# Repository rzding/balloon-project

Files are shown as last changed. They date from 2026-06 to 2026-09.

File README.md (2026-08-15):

# SSI high-altitude balloon project

**Firmware:** [`balloon-project-stm32mx/`](balloon-project-stm32mx/) — STM32F411 flight-computer firmware (build, flash, and coding standards).

**Standards and phases:** [`Software Documents/Main Developmental Roadmap.md`](Software%20Documents/Main%20Developmental%20Roadmap.md)

**Verification workflow:** [`Software Documents/Firmware Development Guidelines.md`](Software%20Documents/Firmware%20Development%20Guidelines.md) — deferred hardware, host tests, bench backlog (roadmap §21). Software-complete unblocks the next driver phase; hardware exit is ticked during bring-up week, not before coding the next phase.

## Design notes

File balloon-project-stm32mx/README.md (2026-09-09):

# STM32 flight-computer firmware

STM32F411CEU6 firmware for the SSI high-altitude balloon flight computer. CubeMX generates `Core/`; application code lives in `App/`.

## Coding standards

Follow [Software Documents/Main Developmental Roadmap.md](../Software%20Documents/Main%20Developmental%20Roadmap.md) **§3** (architecture and coding practices) and [Firmware Development Guidelines.md](../Software%20Documents/Firmware%20Development%20Guidelines.md) (verification, deferred HW, host tests). In short:

- Layered design: `main` → `app_init` / `app_run` → drivers → `spi_bus` → HAL
- Edit CubeMX output only inside `/* USER CODE BEGIN/END */` blocks
- One device = one module (`foo.c` / `foo.h`); public APIs use `bool *_init(void)` and read/poll functions
- Fail-operational: set `error_flags`; never block the mission loop on subsystem faults
- No `malloc` in the flight loop; fixed-size buffers; finite HAL timeouts
- Deferred hardware checks: track in roadmap **§21 Bench verification backlog** until bring-up week. Software-complete of a phase unblocks the next driver phase; HW exit stays in §21 until the board is exercised.

**Host unit tests** (pure logic, no HAL): `tests/host/` — run manually; see `tests/host/README.md`. Cursor agents document run commands but do not execute tests by default.

`.clang-format` is deferred (not required for Phase F0).

## Build

From this directory:

```bash
make clean && make
```

Requires `arm-none-eabi-gcc` (e.g. STM32CubeCLT). Artifacts are written to `build/` (gitignored):

- `build/balloon-project-stm32mx.elf`
- `build/balloon-project-stm32mx.hex`
- `build/balloon-project-stm32mx.bin`

### APRS dry-run vs RF (F10.4 / O6)

Default build is **dry-run** (`APRS_RF_ENABLE=0`): the APRS state machine still encodes and may drive AFSK on PA0, but **PTT stays high** (no RF). Inspect `g_aprs_last_info` / `g_aprs_ok` under GDB. Host proof of frame encode: `tests/host` → `./test_aprs_ax25`.

Licensed on-air only:

```bash
make clean && make APRS_RF_ENABLE=1
```

Do not enable RF without a callsign and license.

## Add a new App module

1. Add `App/Inc/foo.h` and `App/Src/foo.c` (one module = one `.c` / `.h` pair).
2. List `App/Src/foo.c` in Makefile `C_SOURCES` (re-add App entries after CubeMX Makefile regen).
3. `#include "foo.h"` from callers; `-IApp/Inc` is already in `C_INCLUDES`.
4. Regenerate IDE IntelliSense DB: `make compile_commands`.

## IDE IntelliSense (Cursor / VS Code)

Repo-root workspace config (keeps editor diagnostics aligned with the Makefile):

- `compile_commands.json` — same defines/includes as `make`
- `.clangd` — clangd + `arm-none-eabi-gcc` query-driver
- Repo `.vscode/c_cpp_properties.json` + `.vscode/settings.json`

After adding App sources, run `make compile_commands`, then **Developer: Reload Window** if squiggles remain.

## SWD / flash

**Hardware:** ST-Link (or Nucleo as SWD bridge) to the flight-computer SWD header (SWDIO, SWDCLK, GND, 3V3, NRST as wired on the PCB).

**Tooling (any one):**

- STM32CubeProgrammer — flash `build/balloon-project-stm32mx.elf` or `.bin`
- `st-flash write build/balloon-project-stm32mx.bin 0x08000000`
- OpenOCD + GDB — load `build/balloon-project-stm32mx.elf`

**Expected behavior after reset:** `main` → peripheral init → `app_init()` → `while (1) { app_run(); }`

## Layout

```text
balloon-project-stm32mx/
  Core/          # CubeMX — edit ONLY USER CODE regions
  App/
    Inc/         # Public headers per module
    Src/         # One .c per module
  Makefile       # Every App/Src/*.c listed; -IApp/Inc
```

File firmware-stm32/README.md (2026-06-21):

Folder containing all firmware code for STM32 Computer

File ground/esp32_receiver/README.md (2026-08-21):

# ESP32 ground station receiver

Receives packet v1 telemetry from the flight computer's RFM95W and prints decoded
fields over USB serial. No WiFi or BLE — the ESP32 stays wired to the laptop.

Sketch: [`esp32_receiver.ino`](esp32_receiver.ino)

## Hardware

| Item | Notes |
|---|---|
| ESP32 dev board | any; pins below are remappable |
| Adafruit RFM95W LoRa breakout | product [3072](https://www.adafruit.com/product/3072), 915 MHz |
| 915 MHz antenna | 3.12" (~79 mm) solid-core wire on the ANT pad, or SMA |

The breakout has an onboard 3.3 V regulator and level shifting, so it is 3–6 V
tolerant on Vin and safe on the ESP32's 3.3 V logic.

## Wiring

| Breakout | ESP32 | Notes |
|---|---|---|
| Vin | 3V3 | regulated on-board |
| GND | GND | |
| EN | *not connected* | pulled high to Vin by default |
| SCK | D18 | |
| MISO | D19 | |
| MOSI | D15 | remapped via the GPIO matrix |
| CS | D5 | |
| RST | D4 | library pulses this low to reset the radio |
| G0 | *not connected* | see below |
| ANT | antenna | **required — do not transmit or receive without one** |
| DIO1–DIO5 | *not connected* | |

`G0` (DIO0) is unused because the sketch polls with `LoRa.parsePacket()` rather
than using an interrupt. If you switch to `LoRa.onReceive()`, wire G0 to a
general-purpose pin and set `PIN_DIO0`.

**Avoid GPIO2 for G0.** It is a boot-strapping pin, and G0 is driven by the
radio, so the radio could hold it at an arbitrary level while the ESP32 is
deciding how to boot.

## Software setup

1. **ESP32 board support** — Arduino IDE → Settings → *Additional Board Manager
   URLs*:
   ```
   https://espressif.github.io/arduino-esp32/package_esp32_index.json
   ```
   Then Tools → Board → Boards Manager → install **esp32 by Espressif Systems**.

2. **Library** — Tools → Manage Libraries → install **LoRa by Sandeep Mistry**.

   Do **not** use RadioHead, even though Adafruit's guide does. `RH_RF95`
   prepends a 4-byte TO/FROM/ID/FLAGS header to every packet; the flight
   firmware sends a raw 28-byte payload, so RadioHead would consume the first
   four bytes and corrupt every packet.

3. Open `esp32_receiver.ino`, select your board and port, upload.

4. Serial Monitor at **115200 baud**.

## Expected output

```
SSI Balloon ground station — packet v1 receiver
Radio up: 915.0 MHz  SF8  BW125k  CR4/5  sync 0x12  CRC on
Listening...

[1/1] seq=0  t=5001 ms  state=0
    gps      : 0.0000000, 0.0000000   alt=0 m   sats=0
    baro alt : 138 m
    temp     : 22.94 C
    batt     : n/a
    flags    : 0x2e
    link     : rssi=-42 dBm  snr=9.8 dB
```

The counter is `[valid/total]`, so `[7/9]` means nine packets arrived and two
failed version or CRC checks — useful for judging link margin at range.

Zeroed GPS fields are normal indoors; the flight firmware still beacons without
a fix so the RF link can be tested independently of GPS.

## Modem settings

Every parameter below must match
[`App/Inc/lora.h`](../../balloon-project-stm32mx/App/Inc/lora.h). If the flight
side changes, change the sketch too or nothing will decode.

| Parameter | Value |
|---|---|
| Frequency | 915.0 MHz |
| Spreading factor | SF8 |
| Bandwidth | 125 kHz |
| Coding rate | 4/5 |
| Header | explicit |
| CRC | on |
| Sync word | `0x12` (private; not LoRaWAN `0x34`) |
| Preamble | 8 symbols |

Payload is 28 bytes, packet v1, per
[`App/Inc/packet.h`](../../balloon-project-stm32mx/App/Inc/packet.h). All
multi-byte fields are big-endian; the trailing CRC16 (CCITT-FALSE, init
`0xFFFF`, poly `0x1021`) covers bytes 0–25.

## Troubleshooting

| Symptom | Meaning |
|---|---|
| `ERROR: radio not found` | ESP32 cannot reach the radio over SPI — check wiring, Vin, and that EN is not pulled low |
| `Listening...` then silence | Radio is fine but nothing is arriving. RF problem: antennas, distance, or the flight board is not transmitting |
| `BAD PACKET ... raw=` | Receiving RF but failing version/CRC. The raw hex is printed — decode it by hand with [`ground/decode_packet`](../decode_packet.c) |

Keep the two boards at least a metre apart. At +17 dBm, antennas touching can
overload the receiver front end and produce exactly the "nothing received"
symptom you would blame on a wiring fault.

## Checking the flight side independently

If nothing is received, confirm the flight board is actually transmitting before
suspecting the receiver. Attach the debugger and watch these globals in the
Expressions view (see `App/Src/app.c`):

| Expression | Meaning |
|---|---|
| `g_beacon_attempts` | beacons tried |
| `g_beacon_ok` | `lora_tx()` returned true |
| `g_beacon_fail` | `lora_tx()` returned false |
| `g_beacon_wire` | the 28 bytes on air — copy as hex into `ground/decode_packet` |

`g_beacon_ok` climbing means the radio reported TxDone, so the problem is on the
RX side or in the air, not the flight firmware.

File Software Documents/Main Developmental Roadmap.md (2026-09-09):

> **Project:** SSI High-Altitude Balloon Flight Computer  
> **MCU:** STM32F411CEU6 | **Firmware tree:** `balloon-project-stm32mx/`

---

## Document control

| Field | Value |
|---|---|
| Title | Main Developmental Roadmap |
| Location | `Software Documents/Main Developmental Roadmap.md` |
| Status | Draft for team review → Active after approval |
| Audience | Firmware engineers (including first-time embedded), hardware, ops |
| Related | HAB systems plan; KiCad schematics; `balloon-project-stm32mx.ioc`; datasheets; [Firmware Development Guidelines.md](Firmware%20Development%20Guidelines.md) |
| Source of truth (HW) | KiCad + CubeMX (not early `Balloon Project.md` part tables) |

### Revision history

| Rev | Date | Author | Notes |
|---|---|---|---|
| 0.1 | 2026-08-05 | Firmware planning | Initial roadmap from as-built HW + team Q&A |
| 0.2 | 2026-08-05 | Firmware | F0.1 complete: `App/` stubs (`app`, `error_flags`) + `main.c` wiring |
| 0.3 | 2026-08-05 | Firmware | F0.2 complete: Makefile `C_SOURCES` + `-IApp/Inc`; clean rebuild verified |
| 0.4 | 2026-08-05 | Firmware | F0.3 complete: USART1 @ 9600 (USER CODE re-init + `.ioc`) |
| 0.5 | 2026-08-05 | Firmware | F0.4 complete: error-flag framework (`*_ok` accessors; fail-soft `app_run`) |
| 0.6 | 2026-08-05 | Firmware | F0.5 complete: coding-standard README + F0 entry/exit sync |
| 0.7 | 2026-08-06 | Firmware | F1.1 complete: `spi_bus` clock policy (DIV128 ~0.78 MHz), `spi_bus_init` / `spi_bus_set_prescaler`, max-clock comment block |
| 0.8 | 2026-08-06 | Firmware | F1.2 complete: `spi_bus_transfer` CS assert/release, timeout/error CS restore + `HAL_SPI_Abort` |
| 0.9 | 2026-08-06 | Firmware | F1.3 complete: `spi_bus_read_reg8` / `spi_bus_write_reg8` (IMU/LoRa bit-7 R/W convention) |
| 0.10 | 2026-08-06 | Firmware | F2.1 complete: `imu` WHO_AM_I (`0x75`→`0x47`), `imu_init` / `imu_is_ok`, fail-soft `error_flags` |
| 0.11 | 2026-08-06 | Firmware | F2.2 complete: soft reset, SPI-only + AFSR off, FS/ODR 100 Hz ±16 g/±2000 dps, LN power, read-back verify |
| 0.12 | 2026-08-06 | Firmware | Guidelines doc + §21 bench backlog + Cursor rules; deferred-HW / host-test / manual-run policy |
| 0.13 | 2026-08-06 | Firmware | F2.3 sample read (`imu_read`, scale helpers) + F2.4 ongoing health; host `test_imu_scale`; F2 software complete, HW → §21 |
| 0.14 | 2026-08-09 | Firmware | F2 software verification closed: host `test_imu_scale` manual pass; HW exit remains §7.3 / §21 |
| 0.15 | 2026-08-09 | Firmware | F3.1 complete: `baro` reset + PROM C1–C6 + CRC4, `baro_init` / `baro_is_ok`, host `test_ms5611_crc`; F3.2–F3.4 open; HW → §21 |
| 0.16 | 2026-08-09 | Firmware | F3.1 host `test_ms5611_crc` fix — AN520 test vector; manual pass |
| 0.17 | 2026-08-15 | Firmware | F3.2 complete: D1/D2 OSR 4096 conversion, `baro_read_raw`, host `test_ms5611_adc`; F3.3–F3.4 open; HW → §21 |
| 0.18 | 2026-08-15 | Firmware | F3.3 complete: compensation (1st/2nd order), ISA altitude helper, host `test_ms5611_comp`; F3.4 open; HW → §21 |
| 0.19 | 2026-08-15 | Firmware | F3.4 complete: `baro_sample_t`, `baro_read` (raw + compensate + ISA), host composition in `test_ms5611_comp`; F3 software complete; HW → §21 |
| 0.20 | 2026-08-15 | Firmware | Software vs HW gate wording aligned across phases; proceed-rule explicit in §3.5, §4, §20, F0–F10, §21 |
| 0.21 | 2026-08-15 | Firmware | F4.1 complete: `temp` MAX31865 config (VBIAS, 3-wire, 60 Hz, normally off), `temp_init` / `temp_is_ok`; F4.2–F4.3 open; HW → §21 |
| 0.22 | 2026-08-15 | Firmware | F4.2 complete: 1-shot RTD read, unpack/ohm/CVD helpers, `temp_read_raw`, host `test_max31865_cvd`; F4.3 open; HW → §21 |
| 0.23 | 2026-08-15 | Firmware | F4.2 CVD inverse quadratic root fix (`temp_pt1000_ohm_to_c`); host `test_max31865_cvd` manual pass |
| 0.24 | 2026-08-15 | Firmware | F4.3 complete: `temp_sample_t`, `temp_sample_from_raw`, `temp_read`; F4 software complete; HW → §21 |
| 0.25 | 2026-08-15 | Firmware | F4.3 host `test_max31865_cvd` manual pass; remove unused `assert_i16` |
| 0.26 | 2026-08-19 | Firmware | F5.1 complete: USART1 RXNE IRQ ring, `gps_poll` LF line extract, `gps_init`/`gps_is_ok`, host `test_gps_rx`; F5.2–F5.4 open; HW → §21 |
| 0.27 | 2026-08-19 | Firmware | F5.1 host `test_gps_rx` manual pass (test harness fix: sequential drain, wrap trailing line) |
| 0.28 | 2026-08-19 | Firmware | F5.2 complete: GGA/RMC NMEA parse, `gps_sample_t`, `gps_get_sample`, host `test_gps_nmea`; F5.3–F5.4 open; HW → §21 |
| 0.29 | 2026-08-19 | Firmware | F5.3 complete: `gps_sample_has_fix` / `gps_has_fix`; host `test_gps_nmea` extended; F5 software-complete; F5.4 optional/open; HW → §21 |
| 0.30 | 2026-08-19 | Firmware | Gated `APP_BENCH_BUS_EXERCISE` (`make BENCH=1`) + [Logic Analyzer Bench Guide.md](Logic%20Analyzer%20Bench%20Guide.md); §21 F1–F5 procedures updated; F2–F5 HW exit still open |
| 0.31 | 2026-08-20 | Firmware | F7.1 complete: `lora` RESET + VERSION (`0x42`→`0x12`), `lora_init` / `lora_is_ok`, fail-soft `error_flags`; F7.2–F7.4 open; HW → §21 |
| 0.32 | 2026-08-20 | Firmware | F7.2 complete: LoRa modem config 915 MHz SF8/BW125/CR4/5/CRC, sync 0x12, PA_BOOST +17 dBm, LoRa standby; host `test_lora_frf`; F7.3–F7.4 open; HW → §21 |
| 0.33 | 2026-08-20 | Firmware | Fix F7.2 `test_lora_frf` golden Frf vectors (`0xE4C000` / `0xD90000`); §21 bench Frf text corrected |
| 0.34 | 2026-08-20 | Firmware | F7.3 complete: `lora_tx` FIFO + DIO0 poll (1000 ms timeout), `lora_get_seq`; F7.4 open; HW → §21 |
| 0.35 | 2026-08-20 | Firmware | F7.4 complete: `packet.h` v1 pack/unpack/CRC-16/CCITT-FALSE, host `test_packet_v1`, `ground/decode_packet` RSSI/SNR CLI; F7 software-complete; HW → §21 |
| 0.36 | 2026-08-20 | Firmware | Fix F7.4 `test_packet_v1` minimal CRC golden (`0x18EF` over 26-byte payload); F7 still software-complete; HW → §21 |
| 0.37 | 2026-08-22 | Firmware | F2–F4 hardware bench complete (§7–§9 HW exit + §21 F2–F4); Pre-F8 audit note (docs only); F6 flagged potentially incomplete (deeper dive later); stale F6/F8 entry ticks |
| 0.38 | 2026-08-24 | Firmware | F6 audit + remediation: `spi_bus_acquire`/`release`, SD init ≤400 kHz, USERFatFS mount, host `test_sdlog_name`; F6 software-complete; HW → §21; §3.3 SD CS policy |
| 0.39 | 2026-09-05 | Firmware | Post-F7 audit cleanup: confirm F0–F7 soft-complete / F8 next; drop stale `BENCH=1` docs; freeze packet `flags` OK polarity; §4 28B packet; F10 F5 entry tick |
| 0.40 | 2026-09-05 | Firmware | F8.1 mission SM: `mission.h`/`mission.c`, app wire, host `test_mission_sm`; F8 in progress (F8.2–F8.4 open) |
| 0.41 | 2026-09-05 | Firmware | F8.2 schedulers: `schedule.h`/`schedule.c`, state LoRa/camera periods, host `test_schedule`; F8.3 open |
| 0.42 | 2026-09-05 | Firmware | F8.3 packetizer: `packetizer_fill`/`pack`, app wire, host `test_packetizer`; F8 software path complete pending §21 HW |
| 0.43 | 2026-09-05 | Firmware | F8.4 complete: richer host edge profiles in `test_mission_sm`; F8 software exit confirmed; HW → §21 |
| 0.44 | 2026-09-05 | Firmware | F10.1 complete: `aprs` PD/PTT idle high, USART2 9600, AT connect/group/volume/filter; host `test_aprs_at`; F10.2–F10.4 open; HW → §21 |
| 0.45 | 2026-09-08 | Firmware | F10.2 complete: AX.25 UI / APRS position encode + TIM2 Bell 202 AFSK; host `test_aprs_ax25`; no PTT TX; F10.3–F10.4 open; HW → §21 |
| 0.46 | 2026-09-08 | Firmware | F10.3 complete: non-blocking PTT→AFSK SM, 60 s schedule, `APRS_RF_ENABLE=0` default; F10.4 open; HW → §21 |
| 0.47 | 2026-09-08 | Firmware | F10.4 complete: dry-run logging (`g_aprs_*` / `g_aprs_last_info`), soft exit (§15.3); phase software-complete; HW → §21 |

### How to use this document

1. Pick a phase whose **entry criteria** are met.  
2. Implement only that phase’s **work packages** (subsections).  
3. Tick **software** verification before starting the next sequential phase. Do **not** wait on hardware exit — those items go to **§21** until bring-up week (see [Firmware Development Guidelines.md](Firmware%20Development%20Guidelines.md)). Still honor **entry criteria** (F1 before SPI slaves; F5 parallel after F0; F9 ArduCAM SKU; F10 license for on-air; F11/F12 require hardware).  
4. Do not skip phases that share the SPI bus (F1 before F2–F4, F6, F7, F9).  
5. Record open defects in a simple issue list; blockers stay in §18.  
6. F11 (HIL) and F12 (flight readiness) still require real hardware — deferred §21 items do not substitute.

---

## 1. Purpose and scope

### 1.1 Purpose

Provide a **phase-gated, modular firmware development roadmap** so any engineer can implement one work package safely, with industry-standard practices (layered drivers, fail-operational behavior, explicit entry/exit criteria, verification).

### 1.2 In scope

- Application firmware on STM32F411 (HAL + `App/` modules)
- Drivers: SPI bus, IMU, barometer, RTD temp, GPS, microSD/FatFS, LoRa, ArduCAM, APRS
- Mission state machine, telemetry packetizer, SD logging, imaging to SD
- Ground-station compatibility requirements for LoRa
- Integration, HIL, and flight-readiness gates

### 1.3 Out of scope

- PCB redesign / KiCad changes (except documenting needed bodges)
- Raspberry Pi / OpenHD (not the flight imaging path)
- Battery fuel-gauge (no ADC on board)
- Regulatory filings (NOTAM, etc.) except APRS license dependency

### 1.4 Mission success (software view)

Recoverable flight with: valid GPS (when sky visible), baro/temp/IMU logged, LoRa telemetry heard on ground, SD black box intact, photos on SD when camera works, APRS when licensed and configured.

---

## 2. System context (read once)

### 2.1 Boards

| Board | Role |
|---|---|
| Flight computer PCB | STM32 + sensors + LoRa + GPS + microSD + ArduCAM connector + power |
| SSI APRS daughterboard | DRA818V; UART + PTT + PD + audio from flight computer |

### 2.2 Confirmed as-built parts (team Q&A)

| Function | Part | Interface |
|---|---|---|
| MCU | STM32F411CEU6 @ 100 MHz (12 MHz HSE) | — |
| IMU | ICM-42688-P | SPI1 + `IMU_CS` + `IMU_INT1` |
| Barometer | MS5611-01BA03 | SPI1 + `BARO_CS` |
| Temperature | MAX31865 + **PT1000** 3-wire | SPI1 + `Temp_CS` |
| GPS | MAX-M10S | USART1 **9600 8N1** |
| LoRa | RFM95W 915 MHz | SPI1 + CS/RESET/DIO0 |
| Storage | microSD | SPI1 + CS; detect **high = present** |
| Camera | ArduCAM on `CAM_CONN` | SPI1 + I2C1 (SKU TBD — Gabe) |
| APRS | DRA818V (separate PCB) | USART2 + PTT/PD + PWM audio (**wired**) |

### 2.3 Locked electrical software constants

| Item | Value |
|---|---|
| GPS baud | 9600 (fixed in F0.3: USER CODE re-init + `.ioc`; MAX-M10S default) |
| SD detect | High = present |
| APRS PTT | Low = TX, High = RX |
| APRS PD | Low = sleep, High = normal |
| APRS cable | Mirrored, pins face-to-face |
| SPI bring-up clock | ~1 MHz shared (`SPI_BAUDRATEPRESCALER_128` → ~0.78 MHz on 100 MHz APB2; raise later only if proven) |
| Photos | Store on microSD |
| LEDs / ARM switch / battery ADC | Not available — software must not depend on them |

### 2.4 Bus map

```text
SPI1 (PA5/PA6/PA7): IMU, MS5611, MAX31865, RFM95W, microSD, ArduCAM
I2C1 (PB6/PB7):     ArduCAM config only
USART1 (PA9/PA10):  GPS @ 9600
USART2 (PA2/PA3):   APRS AT commands
TIM2 CH1 (PA0):     APRS AFSK PWM
```

---

## 3. Architecture and coding standards (mandatory)

### 3.1 Layered architecture

```text
main.c (USER CODE only)  →  app_init / app_run
                              ↓
                         mission + packet
                              ↓
              drivers (imu, baro, temp, gps, sdlog, lora, camera, aprs)
                              ↓
                         spi_bus (CS ownership)
                              ↓
                         STM32 HAL
```

### 3.2 Repository layout

```text
balloon-project-stm32mx/
  Core/          # CubeMX — edit ONLY /* USER CODE BEGIN/END */ regions
  App/
    Inc/         # Public headers per module
    Src/         # One .c per module
  Makefile       # Every App/Src/*.c listed; -IApp/Inc
Software Documents/
  Main Developmental Roadmap.md   # THIS FILE
```

### 3.3 Coding practices (industry baseline for this project)

| Practice | Rule |
|---|---|
| Modularity | One device = one module (`imu.c` / `imu.h`); no cross-calling internals |
| CubeMX safety | Never edit generated code outside USER CODE blocks |
| APIs | `bool *_init(void);` + read/poll functions; return false on failure |
| Fail-operational | Set `error_flags`; **never** infinite-block the mission loop |
| Timeouts | All HAL SPI/I2C/UART calls use finite timeouts |
| Memory | No `malloc` in flight loop; fixed-size buffers only |
| Concurrency | v1 = bare-metal superloop; ISRs only set flags / push bytes |
| SPI | Single `spi_bus` owner; one CS low at a time. Register slaves use per-call CS in `spi_bus_transfer`. **microSD** holds CS for one protocol frame (cmd/data/CRC) via `spi_bus_acquire` … manual CS … `spi_bus_release` — never leave `microSD_CS` low between FatFs ops |
| Types | Fixed-width (`uint8_t`, `int32_t`); explicit endianness in packets |
| Logging | Prefer SD CSV; optional SWD debug builds only |
| Versions | Boot log / packet field includes firmware version string |
| Reviews | PR for each phase exit when possible |

### 3.4 Module API template

Every driver header should follow this pattern:

```c
#pragma once
#include <stdbool.h>
#include <stdint.h>

typedef struct { /* fields */ } imu_sample_t;

bool imu_init(void);                 /* false => hardware/ID fail */
bool imu_read(imu_sample_t *out);    /* false => comms fail */
bool imu_is_ok(void);                /* last known health */
```

### 3.5 Definition of Done (all phases)

Two levels — do not conflate them.

**Software-complete (unblocks next coding phase):**

1. Code merged (or committed) under `App/` with Makefile updated  
2. Work-package checklists ticked  
3. Software verification executed and noted (pass/fail + date): clean `make clean && make`; host tests authored when the phase has pure logic; fail-soft paths documented — **does not require a board**  
4. No critical defect open that blocks the next phase’s entry criteria  
5. Public header documented enough for another engineer to call the API  

**Phase exit complete (full close):**

- Software-complete **and** hardware exit criteria ticked after bench, **or** hardware exit still open in §21 — in that case phase status must say “HW exit open” and the phase must **not** be claimed fully complete.

**Entry-criteria shorthand:** when a later phase says “F1 complete” or “F3 software-complete,” that means **software-complete** of that dependency, not bench verification ticked.

---

## 4. Phase overview

| Phase | Name | Primary deliverable | Depends on |
|---|---|---|---|
| **F0** | Foundation & tooling | `App/` skeleton, standards, GPS baud 9600 | Assembled board or Nucleo path |
| **F1** | SPI bus services | `spi_bus` @ ~1 MHz | F0 |
| **F2** | IMU driver | ICM-42688-P samples | F1 |
| **F3** | Barometer driver | MS5611 pressure/altitude | F1 |
| **F4** | Temperature driver | MAX31865 PT1000 °C | F1 |
| **F5** | GPS driver | NMEA fix @ 9600 | F0 |
| **F6** | SD logging | FatFS append log | F1 |
| **F7** | LoRa telemetry TX | RFM95W packets | F1, packet draft, ground RX |
| **F8** | Mission + packetizer | State machine + 28B packet v1 | F2–F5 (soft), F7 for live TX |
| **F9** | ArduCAM → SD | Images on card | F1, F6, **Gabe SKU** |
| **F10** | APRS | Position beacons | F5, **callsign/license** |
| **F11** | System integration (HIL) | End-to-end on hardware | F0–F10 as available |
| **F12** | Flight readiness | Software freeze + checklist | F11 pass |

**Parallelism:** F5 (GPS/UART) can proceed in parallel with F2–F4 after F0. F9/F10 can be prepared offline but must not block F7/F8 for chase-critical path.

**Proceed rule (software vs bench):**

- Sequential driver work **F2–F7** proceeds when dependencies are **software-complete**; bench validation is §21 bring-up week, not a coding blocker.
- **F8** may start when F3 and/or F5 altitude **APIs** exist (software); live TX needs F7 software-complete; ops RX node is for HW exit.
- **F11/F12** require real hardware; §21 per-subsystem bench does not substitute for F11.

**Chase-critical MVP path:** F0 → F1 → F2 → F3 → F4 → F5 → F6 → F7 → F8  
**Full mission path:** MVP + F9 + F10 + F11 + F12  

---

## 5. Phase F0 — Foundation and tooling

**Phase status:** software verification complete (2026-08-05); hardware exit open (§5.4 / §21). Full phase exit pending bench — see §21 F0.

### 5.0 Objective

Establish a safe, regeneratable project structure and correct base peripheral config so later phases only add modules.

### 5.1 Entry criteria

- [x] Repo builds with existing Makefile (or known build errors documented)
- [x] SWD programming path identified (ST-Link / Nucleo) — documented in `balloon-project-stm32mx/README.md`
- [x] Team agrees modular `App/` layout (flexible per Q13; this roadmap mandates it)

### 5.2 Work packages

#### F0.1 — Create `App/` tree

**Status:** complete (2026-08-05)

- [x] Create `App/Inc/` and `App/Src/` (directories pre-existed; populated with stubs)
- [x] Add stub files: `app.c/h`, `error_flags.c/h`
- [x] Wire `main.c` USER CODE to call `app_init()` / `app_run()`

#### F0.2 — Makefile integration

**Status:** complete (2026-08-05)

- [x] Add all new `.c` files to `C_SOURCES`
- [x] Add `-IApp/Inc` to includes
- [x] Confirm clean rebuild

**How to add a new App module (3 steps):**

1. Add `App/Inc/foo.h` and `App/Src/foo.c` (one module = one `.c` / `.h` pair).
2. List `App/Src/foo.c` in Makefile `C_SOURCES` (re-add App entries after CubeMX Makefile regen).
3. `#include "foo.h"` from callers; `-IApp/Inc` is already in `C_INCLUDES` after F0.2.

#### F0.3 — Fix USART1 baud to 9600

**Status:** complete (2026-08-05)

- [x] Update `.ioc` **and** set `huart1.Init.BaudRate = 9600` in USER CODE after `MX_USART1_UART_Init` (re-init via `HAL_UART_Init`)
- [x] Document: GPS default is 9600 per datasheet/team (comment in `main.c` §USART1_Init 2; §2.3 constant table)

#### F0.4 — Error flag framework

**Status:** complete (2026-08-05)

- [x] Bitflags for `imu_ok`, `baro_ok`, `temp_ok`, `gps_ok`, `sd_ok`, `lora_ok`, `cam_ok`, `aprs_ok` via `error_flags_*_ok()` / `error_flags_set_*_ok()` (ERR_FLAG bit set = fault)
- [x] `app_run` must continue even if flags are false (queries `error_flags_get()`; no blocking on faults)

#### F0.5 — Coding standard note in repo (short)

**Status:** complete (2026-08-05)

- [x] Point developers to this roadmap §3 (`balloon-project-stm32mx/README.md` + root `README.md` pointer)
- [x] Optional: `.clang-format` later (deferred; not required to exit F0)

### 5.3 Deliverables

- Compiling firmware with empty `app_run()` loop
- USART1 @ 9600
- Documented how to add a new module (3 steps: files, Makefile, include)

### 5.4 Verification / exit criteria

**Software verification (closed 2026-08-05):**

- [x] Project builds without errors (verified 2026-08-05)
- [x] Baud change present for USART1
- [x] Another engineer can add `App/Src/foo.c` using the documented steps (`balloon-project-stm32mx/README.md` + §5.2 F0.2)

**Hardware exit (pending bench — tick when §21 F0 procedure passes):**

- [ ] Firmware flashes and reaches `while(1)` — flash procedure documented 2026-08-05; physical flash pending bench ST-Link (see §21)

---

## 6. Phase F1 — SPI bus services

**Phase status:** software verification complete (2026-08-06); hardware exit open (§6.4 / §21). Full phase exit pending bench — see §21 F1.

### 6.0 Objective

Own the shared SPI1 bus safely for six slaves.

### 6.1 Entry criteria

- [x] F0 complete (software; physical bench flash still pending per §5.4)
- [x] All CS pins idle high after `MX_GPIO_Init` (already Cube default)

### 6.2 Work packages

#### F1.1 — Clock policy

**Status:** complete (2026-08-06)

- [x] Set SPI prescaler for ~0.5–1 MHz (`SPI_BAUDRATEPRESCALER_128` → ~0.78 MHz; not Cube ÷2 / ~50 MHz)
- [x] Optional helper `spi_bus_set_prescaler()` for later per-device speed

#### F1.2 — Transfer API

**Status:** complete (2026-08-06)

- [x] `spi_bus_transfer(GPIO_TypeDef *cs_port, uint16_t cs_pin, const uint8_t *tx, uint8_t *rx, uint16_t len, uint32_t timeout_ms)`
- [x] Assert CS low → HAL transfer → CS high
- [x] Guarantee CS high on timeout/error paths (`HAL_SPI_Abort` after deassert)

#### F1.3 — Register helpers (optional but recommended)

**Status:** complete (2026-08-06)

- [x] `spi_bus_read_reg8` — IMU/LoRa-style read (reg | 0x80, dummy byte, value in second RX byte)
- [x] `spi_bus_write_reg8` — IMU/LoRa-style write (reg & 0x7F, value)

### 6.3 Deliverables

- `spi_bus.c` / `spi_bus.h`
- Comment block listing max clocks per device (MAX31865 ≤5 MHz, etc.)

### 6.4 Verification / exit criteria

**Software verification (closed 2026-08-06):**

- [x] Clean build (`make clean && make` in `balloon-project-stm32mx/`)
- [x] `spi_bus_transfer` always deasserts CS on success and error paths (code-path verified)
- [x] Timeout path calls `HAL_SPI_Abort` after CS release (code-path verified)

**Hardware exit (pending bench — tick when §21 F1 procedure passes):**

- [x] CS lines idle high (meter or analyzer) — Cube default after `MX_GPIO_Init` verified in software; meter pending bench (see §21)
- [x] Dummy transfer does not leave CS stuck low — `spi_bus_transfer` always deasserts CS; analyzer pending bench (see §21)
- [x] Timeout path releases CS — code-path verified in `spi_bus_transfer`; analyzer pending bench (see §21)

---

## 7. Phase F2 — IMU (ICM-42688-P)

**Phase status:** complete (software 2026-08-09; hardware bench 2026-08-22). Full phase exit closed — see §7.3 / §21 F2.

### 7.0 Objective

Prove SPI + first sensor; provide motion data for burst detection later.

### 7.1 Entry criteria

- [x] F1 complete

### 7.2 Work packages

#### F2.1 — Identity

**Status:** complete (2026-08-06)

- [x] Read WHO_AM_I (`0x75`); compare to ICM-42688-P expected ID (`0x47`)
- [x] Fail `imu_init` on SPI error or ID mismatch
- [x] `error_flags_set_imu_ok` + `imu_is_ok()` on init path
- [x] `imu.c` / `imu.h`; Makefile `C_SOURCES`; called from `app_init` fail-soft

#### F2.2 — Configuration

**Status:** complete (2026-08-06)

- [x] Soft reset via `DEVICE_CONFIG` (`0x11`); post-reset WHO_AM_I re-check
- [x] SPI-only interface (`INTF_CONFIG0`); disable AFSR (`INTF_CONFIG1`)
- [x] Accel ±16 g / gyro ±2000 dps at 100 Hz ODR (`GYRO_CONFIG0` / `ACCEL_CONFIG0` = `0x08`)
- [x] Low-noise power (`PWR_MGMT0` = `0x0F`); register read-back verify

#### F2.3 — Sample read

**Status:** complete (2026-08-06)

- [x] `imu_sample_t` with raw accel/gyro XYZ (16-bit LSB)
- [x] Burst SPI read `ACCEL_DATA_X1`..`GYRO_DATA_Z0` (12 bytes) via `spi_bus_transfer`
- [x] `imu_read()` polling API; scale helpers `imu_accel_raw_to_mps2` / `imu_gyro_raw_to_dps`
- [x] Host test `tests/host/test_imu_scale` pass (manual, 2026-08-09)

#### F2.4 — Health

**Status:** complete (2026-08-06)

- [x] `imu_read` success/failure updates `error_flags_set_imu_ok` and `imu_is_ok()`
- [x] `imu_is_ok()` reflects last init or read outcome

### 7.3 Verification / exit criteria

**Software verification (closed 2026-08-09):**

- [x] Clean build (`make clean && make` in `balloon-project-stm32mx/`)
- [x] Host `tests/host/test_imu_scale` pass (manual, 2026-08-09)
- [x] Init failure does not hang MCU — `(void)imu_init()` in `app_init`; `app_run` continues; code-path verified (2026-08-06)

**Hardware exit (closed 2026-08-22 — §21 F2 procedure passed):**

- [x] WHO_AM_I passes on hardware (see §21 F2) — 2026-08-22
- [x] Values change when board is moved/tilted (see §21 F2) — 2026-08-22

---

## 8. Phase F3 — Barometer (MS5611)

**Phase status:** complete (software 2026-08-15; hardware bench 2026-08-22). Full phase exit closed — see §8.3 / §21 F3.

### 8.0 Objective

Pressure and barometric altitude for ascent/float/descent logic.

### 8.1 Entry criteria

- [x] F1 complete (can parallel F2 after F1)

### 8.2 Work packages

#### F3.1 — Reset and PROM

**Status:** complete (2026-08-09)

- [x] SPI reset command (`0x1E`) via `spi_bus_transfer` + `BARO_CS`
- [x] Read calibration coefficients C1–C6 from PROM (all eight words; cache for F3.2+)
- [x] CRC4 check per AN520 / datasheet (recommended — implemented)
- [x] Fail `baro_init` on SPI error, zero PROM word, or CRC mismatch
- [x] `error_flags_set_baro_ok` + `baro_is_ok()` on init path
- [x] `baro.c` / `baro.h`; Makefile `C_SOURCES`; called from `app_init` fail-soft
- [x] Host test `tests/host/test_ms5611_crc` pass (manual, 2026-08-09; AN520 vector)

#### F3.2 — Conversion sequence

**Status:** complete (2026-08-15)

- [x] D1 pressure conversion at OSR 4096 (`0x48`) via `spi_bus_transfer` + `BARO_CS`
- [x] D2 temperature conversion at OSR 4096 (`0x58`)
- [x] Wait max conversion time (`HAL_Delay(10)` ms; datasheet 9.04 ms @ OSR 4096)
- [x] Read 24-bit ADC results via command `0x00` (`baro_be_bytes_to_u24`)
- [x] `baro_raw_t` + `baro_read_raw()` polling API; reject zero ADC / SPI failure
- [x] `baro_read_raw` success/failure updates `error_flags_set_baro_ok` and `baro_is_ok()`
- [x] Host test `tests/host/test_ms5611_adc` (manual run pending)

#### F3.3 — Compensation math

**Status:** complete (2026-08-15)

- [x] First-order integer compensation per datasheet B3 (`dT`, `TEMP`, `OFF`, `SENS`, `P`)
- [x] Second-order compensation when `TEMP < 20 °C` and extra terms when `TEMP < −15 °C`
- [x] `baro_comp_t` with pressure in Pa and temperature in 0.01 °C; `baro_comp_temp_c` / `baro_comp_pressure_hpa`
- [x] ICAO ISA altitude helper `baro_pressure_pa_to_alt_m` (troposphere / 11–20 km / 20–32 km)
- [x] Host-testable `baro_compensate` in `baro.h` (no HAL)
- [x] Host test `tests/host/test_ms5611_comp` (datasheet example + 2nd-order + ISA; manual run pending)

#### F3.4 — API

**Status:** complete (2026-08-15)

- [x] `baro_sample_t` with `pressure_pa`, `temp_centi_c`, `alt_m` (mission / telemetry units)
- [x] `baro_read` = `baro_read_raw` + compensate cached PROM + ISA altitude (`baro_sample_from_raw`)
- [x] Fail-soft health: invalid PROM, SPI, or compensate failure → `baro_set_ok(false)`; success → `baro_set_ok(true)`
- [x] `baro_init` already wired in `app_init` (F3.1); `baro_read` used by bring-up beacon; F8 owns mission rate
- [x] Altitude helper `baro_pressure_pa_to_alt_m` exposed for mission via `baro_sample_t.alt_m`
- [x] Host-testable `baro_sample_from_raw` in `baro.h`; host test in `test_ms5611_comp` (manual run pending)

### 8.3 Verification / exit criteria

**Software verification (F3.1 — 2026-08-09):**

- [x] Clean build (`make clean && make` in `balloon-project-stm32mx/`)
- [x] Host `tests/host/test_ms5611_crc` pass (manual, 2026-08-09; AN520 vector)
- [x] Init failure does not hang MCU — `(void)baro_init()` in `app_init`; `app_run` continues; PROM/CRC fail path sets `error_flags_set_baro_ok(false)`

**Software verification (F3.2 — 2026-08-15):**

- [x] Clean build (`make clean && make` in `balloon-project-stm32mx/`)
- [x] Host `tests/host/test_ms5611_adc` authored (manual run pending)
- [x] `baro_read_raw` fail path does not hang MCU — not called from `app_run`; health updated on read like `imu_read`

**Software verification (F3.3 — 2026-08-15):**

- [x] Clean build (`make clean && make` in `balloon-project-stm32mx/`)
- [x] Host `tests/host/test_ms5611_comp` authored (manual run pending; datasheet B3 golden vector)
- [x] Compensation helpers pure / host-testable; no SPI or `app_run` changes

**Software verification (F3.4 — 2026-08-15):**

- [x] Clean build (`make clean && make` in `balloon-project-stm32mx/`)
- [x] Host `tests/host/test_ms5611_comp` extended with `baro_sample_from_raw` datasheet vector (manual run pending)
- [x] `baro_read` fail path does not hang MCU — not called from `app_run`; health updated on read like `imu_read`

**Hardware exit (closed 2026-08-22 — §21 F3 procedure passed):**

- [x] Indoor pressure ~980–1040 hPa (site-dependent) — 2026-08-22
- [x] Raising board ~1–2 m shows altitude change directionally — 2026-08-22
- [x] PROM/CRC failure handled cleanly on hardware (CRC pass on silicon; inject fault optional) — 2026-08-22

---

## 9. Phase F4 — Temperature (MAX31865 + PT1000)

**Phase status:** complete (software 2026-08-15; hardware bench 2026-08-22). Full phase exit closed — see §9.3 / §21 F4.

### 9.0 Objective

Outside-air temperature via RTD.

### 9.1 Entry criteria

- [x] F1 software-complete
- [x] PT1000 3-wire confirmed (schematic J8 / team; Gabe BOM O2 for confidence — not a coding blocker)

### 9.2 Work packages

#### F4.1 — Config

**Status:** complete (2026-08-15)

- [x] VBIAS on, 3-wire mode, 60 Hz filter, conversion mode normally off (1-shot ready for F4.2)
- [x] CONFIG write `0x92` (VBIAS \| 3WIRE \| fault clear); read-back verify `0x90`
- [x] 10 ms VBIAS settle after config write
- [x] SPI ≤ 5 MHz (F1 ~0.78 MHz bring-up)
- [x] Fail `temp_init` on SPI error or config read-back mismatch
- [x] `error_flags_set_temp_ok` + `temp_is_ok()` on init path
- [x] `temp.c` / `temp.h`; Makefile `C_SOURCES`; called from `app_init` fail-soft

#### F4.2 — Read RTD

**Status:** complete (2026-08-15)

- [x] 1-shot conversion (`CONFIG 0xA0`), `HAL_Delay(60)` ms @ 60 Hz filter
- [x] Burst-read RTD MSB/LSB; `temp_rtd_unpack` (15-bit ADC + FAULT bit)
- [x] On FAULT: read Fault Status `0x07` into `temp_raw_t.fault_status`; fail-soft
- [x] `temp_rtd_adc_to_ohm` (RREF 4300 Ω); `temp_pt1000_ohm_to_c` (IEC CVD, Newton below 0 °C)
- [x] `temp_raw_t` + `temp_read_raw()` polling API; reject zero ADC / SPI failure
- [x] `temp_read_raw` success/failure updates `error_flags_set_temp_ok` and `temp_is_ok()`
- [x] Host test `tests/host/test_max31865_cvd` (unpack + ohm + CVD vectors; manual pass 2026-08-15)
- [x] Sample path landed in F4.2/F4.3; bring-up beacon calls `temp_read`; F8 owns mission rate

#### F4.3 — API + faults

**Status:** complete (2026-08-15)

- [x] `temp_sample_t` with `temp_centi_c` (packet `temp_c_x100`, int16 centi-°C)
- [x] `temp_sample_from_raw` = ohm + CVD → centi-°C; fail on NULL, fault, zero ADC, CVD fail, int16 overflow
- [x] `temp_read` = `temp_read_raw` + `temp_sample_from_raw`; fail-soft `temp_ok` / `error_flags`
- [x] `temp_init` already wired in `app_init` (F4.1); `temp_read` used by bring-up beacon; F8 owns mission rate
- [x] Host-testable `temp_sample_from_raw` in `temp.h`; host test in `test_max31865_cvd` (manual pass 2026-08-15)

### 9.3 Verification / exit criteria

**Software verification (F4.1 — 2026-08-15):**

- [x] Clean build (`make clean && make` in `balloon-project-stm32mx/`)
- [x] Init failure does not hang MCU — `(void)temp_init()` in `app_init`; `app_run` continues; config read-back fail path sets `error_flags_set_temp_ok(false)`
- [x] No `temp_read` in F4.1 — sample API deferred to F4.2/F4.3

**Software verification (F4.2 — 2026-08-15):**

- [x] Clean build (`make clean && make` in `balloon-project-stm32mx/`)
- [x] Host `tests/host/test_max31865_cvd` pass (manual, 2026-08-15; CVD inverse root fix)
- [x] `temp_read_raw` fail path does not hang MCU — not called from `app_run`; health updated on read like `baro_read_raw`
- [x] No `temp_read` in F4.2 — mission API deferred to F4.3

**Software verification (F4.3 — 2026-08-15):**

- [x] Clean build (`make clean && make` in `balloon-project-stm32mx/`)
- [x] Host `tests/host/test_max31865_cvd` extended with `temp_sample_from_raw` (manual pass 2026-08-15)
- [x] `temp_read` fail path does not hang MCU — fail-soft `temp_ok` / `error_flags`; bring-up beacon calls `temp_read`

**Hardware exit (closed 2026-08-22 — §21 F4 procedure passed):**

- [x] Room-temp reading plausible (~15–30 °C) — 2026-08-22
- [x] Hand on probe moves reading — 2026-08-22
- [x] Disconnect fault (if safe to test) sets fault flag — 2026-08-22

---

## 10. Phase F5 — GPS (MAX-M10S)

**Phase status:** F5 software-complete (2026-08-19); F5.4 optional/open; HW exit open (§10.3 / §21). Full phase exit pending bench — see §21 F5.

### 10.0 Objective

Non-blocking NMEA parser providing fix for recovery and APRS/LoRa.

### 10.1 Entry criteria

- [x] F0 software-complete (USART1 @ 9600)

**Hardware exit (not a coding start blocker):** antenna connected for outdoor fix validation — see §10.3.

### 10.2 Work packages

#### F5.1 — RX path

**Status:** complete (2026-08-19)

- [x] USART1 RXNE IRQ → fixed 256-byte ring buffer (overwrite-oldest on overflow)
- [x] `gps_poll()` extracts LF-terminated lines; strips CR; oversize lines discarded
- [x] `gps_init()` / `gps_is_ok()` / `error_flags_set_gps_ok` — `gps_ok` = RX path armed (not fix)
- [x] `gps_copy_line()` for bench/GDB; `gps_usart1_irq()` in `stm32f4xx_it.c` USER CODE
- [x] NVIC USART1 priority 5 in MSP USER CODE; `.ioc` NVIC intent recorded
- [x] `gps.c` / `gps.h`; Makefile `C_SOURCES`; `(void)gps_init()` fail-soft in `app_init`; `gps_poll()` in `app_run`
- [x] Host-testable ring/line helpers in `gps.h`; host `test_gps_rx` (manual pass 2026-08-19)
- [x] No NMEA parser, `gps_has_fix()`, or UBX/baud change in F5.1

#### F5.2 — Sentence parser

**Status:** complete (2026-08-19)

- [x] Talker-agnostic GGA/RMC detect (`$GP`, `$GN`, etc. via bytes 3–5)
- [x] NMEA 0183 XOR checksum validation; reject on mismatch (fail-soft, keep last good sample)
- [x] GGA: fix quality, sats, altitude (m), lat/lon → `lat_e7`/`lon_e7`, UTC time
- [x] RMC: status A/V → `rmc_valid`, lat/lon, time, date
- [x] `gps_sample_t` + `gps_get_sample()`; integer-only `ddmm` → e7 (no libm)
- [x] `gps_poll()` parses **every** complete line (GGA + RMC in one poll cycle)
- [x] Host-testable parse helpers in `gps.h`; host `test_gps_nmea` (manual pass 2026-08-19)
- [x] No `gps_has_fix()` in this WP (F5.3); sample API deferred to F5.2/F5.3

#### F5.3 — Fix validity

**Status:** complete (2026-08-19)

- [x] `gps_sample_has_fix()` host-testable inline in `gps.h` — `lat_lon_valid` AND (`fix_quality >= 1` OR `rmc_valid`)
- [x] `gps_has_fix()` inspects merged `s_sample`; not tied to bytes received or `gps_ok`
- [x] Indoor / no lock: quality 0 + RMC V → false even when sentences parse
- [x] OR rule (not AND GGA+RMC) — either sentence type can assert fix
- [x] `gps_ok` unchanged — RX armed only; no `error_flags` change on fix
- [x] Bring-up beacon uses `gps_get_sample` (fix fields when valid); F8 may gate on `gps_has_fix`
- [x] Host `test_gps_nmea` extended with fix-validity vectors (manual pass 2026-08-19)

#### F5.4 — Optional UBX config (later)

- Raise baud to 115200 only after both sides agreed; not required for exit

### 10.3 Verification / exit criteria

**Software verification (F5.1 — 2026-08-19):**

- [x] Clean build (`make clean && make` in `balloon-project-stm32mx/`)
- [x] Host `tests/host/test_gps_rx` pass (manual, 2026-08-19; sequential two-line drain + last-line-wins; wrap trailing line)
- [x] `gps_poll()` non-blocking — drains ring only; no UART blocking in superloop
- [x] Fail-soft `gps_ok` / `error_flags_set_gps_ok` on init; `app_run` continues on fault
- [x] No `gps_has_fix()` or NMEA golden-sentence parse in F5.1 — deferred to F5.2/F5.3

**Software verification (F5.2 — 2026-08-19):**

- [x] Clean build (`make clean && make` in `balloon-project-stm32mx/`)
- [x] Host `tests/host/test_gps_nmea` pass (manual, 2026-08-19; GGA/RMC golden sentences, checksum, merge)
- [x] `gps_poll()` parses every complete line; bad checksum does not clear merged sample
- [x] No `gps_has_fix()` in F5.2 — deferred to F5.3
- [x] Bring-up beacon calls `gps_get_sample`; F8 owns mission scheduling

**Software verification (F5.3 — 2026-08-19):**

- [x] Clean build (`make clean && make` in `balloon-project-stm32mx/`)
- [x] Host `tests/host/test_gps_nmea` extended with fix-validity vectors (manual pass 2026-08-19)
- [x] `gps_has_fix()` false without status; true on GGA quality ≥ 1 or RMC A (with parsed lat/lon)
- [x] Full F5 software-complete ticked

**Software verification (F5.4 — optional / open):**

- [ ] UBX baud 115200 (optional; not required for F5 software-complete)

**Hardware exit (pending bench — tick when §21 F5 procedure passes):**

- [ ] Bytes received at 9600 on bench/outdoor
- [ ] Outdoor: valid lat/lon within expected region
- [ ] Antenna connected for outdoor fix tests

---

## 11. Phase F6 — microSD logging (FatFS)

**Phase status:** software verification complete (2026-08-24 — audit remediation + clean `make`; host `test_sdlog_name` authored, manual run pending); hardware exit criteria open (§11.3 / §21). Full phase exit pending bench — see §21 F6.

### 11.0 Objective

Black-box telemetry log; foundation for image storage.

### 11.1 Entry criteria

- [x] F1 software-complete

**Known facts (not coding blockers):** industrial **SDHC/SDXC** microSD for flight (block addressing); detect polarity high = present (see §2).

### 11.2 Work packages

#### F6.1 — Middleware

- [x] Integrate ChaN FatFs or CubeMX FatFS for SPI SD — `user_diskio` → `sd_spi`; `spi_bus_acquire`/`release` for transaction-held CS
- [x] Low clock during card init — `SPI_BAUDRATEPRESCALER_256` (~390 kHz) in `SD_SPI_Init`, restore bring-up default after

#### F6.2 — Mount / file policy

- [x] Check `microSD_detect` then mount — `USERFatFS` / `USERPath`
- [x] Create `FLIGHTxxx.CSV` (or next index) — `sdlog_next_flight_index` / `FLIGHT%03u.CSV`
- [x] Header row once — `FA_CREATE_NEW` + header + `f_sync`

#### F6.3 — Append API

- [x] `sdlog_write_sample(...)` non-fatal on failure
- [x] Periodic `f_sync` — every 10 writes (~50 s at 5 s beacon); sync failure fail-soft

#### F6.4 — Fail-soft

- [x] Missing card ⇒ `sd_ok = false`; mission continues — `(void)sdlog_init()` in `app_init`; close/unmount on hard fail

### 11.3 Verification / exit criteria

**Software verification (tick when work packages land):**

- [x] Clean build (`make clean && make` in `balloon-project-stm32mx/`) — 2026-08-24
- [x] No hang when card absent — fail-soft `sd_ok`; mission continues — code-path verified 2026-08-24
- [x] `sdlog_write_sample` non-fatal on failure — code-path verified 2026-08-24
- [x] Host `tests/host/test_sdlog_name` authored (manual run pending)

**Hardware exit (pending bench — tick when §21 F6 procedure passes):**

- [ ] File visible on PC after flight-sim loop
- [ ] Pull-power mid-write test: document corruption mitigations (flush policy)
- [ ] Industrial microSD exercised on hardware

**CS note:** Analyzer should show short `microSD_CS` low **bursts** (whole CMD/block), not permanent low.

## 12. Phase F7 — LoRa telemetry (RFM95W)

**Phase status:** F7 software-complete (2026-08-20); F7.4 decoder + packet v1 host test; HW exit open (§12.4 / §21). Full phase HW exit pending bench — see §21 F7.

### 12.0 Objective

Ground-receivable telemetry (primary recovery link).

### 12.1 Entry criteria

- [x] F1 software-complete
- [ ] Interim RF + packet proposal accepted or frozen (see §12.2.3)

**Hardware exit / ops (not a coding start blocker):** second RFM95W + Nucleo (or equiv.) for RX — schedule with ops (Q20); see §12.4.

### 12.2 Work packages

#### F7.1 — Reset and probe

**Status:** complete (2026-08-20)

- [x] Hardware reset via `LoRa_RESET` (active-low pulse, POR wait)
- [x] Read VERSION register (`0x42`, expect `0x12` for SX1276)
- [x] Fail `lora_init` on SPI error or ID mismatch
- [x] `error_flags_set_lora_ok` + `lora_is_ok()` on init path
- [x] `lora_get_version()` for bench/GDB
- [x] `lora.c` / `lora.h`; Makefile `C_SOURCES`; `(void)lora_init()` fail-soft in `app_init`
- [x] Clean build verified (2026-08-20); no OpMode/LoRa config, TX, or DIO0 in F7.1

#### F7.2 — Radio config

**Status:** complete (2026-08-20)

- [x] Sleep+LoRa → program modem/PA → LoRa standby (no TX)
- [x] Frequency 915.0 MHz US ISM (`Frf` = `0xE4C000` via `lora_hz_to_frf`; MSB/MID/LSB `0xE4`/`0xC0`/`0x00`)
- [x] SF8, BW125 kHz, CR4/5, explicit header, CRC on (`ModemConfig1`/`2`/`3`)
- [x] Private sync word `0x12` documented in `lora.h` (ground RX must match)
- [x] PA_BOOST +17 dBm, OCP on; no TxContinuousMode, no +20 dBm PaDac overdrive
- [x] Register read-back verify on OpMode, Frf, ModemConfig1/2, SyncWord
- [x] Host `test_lora_frf` pass (915 MHz `0xE4C000`, 868 MHz `0xD90000`; manual, 2026-08-20)
- [x] Clean build verified (2026-08-20); no FIFO TX or DIO0 in F7.2

#### F7.3 — Packet TX

**Status:** complete (2026-08-20)

- [x] `lora_tx(payload, len)` — FIFO burst, OpMode TX, DIO0 poll (1000 ms timeout)
- [x] DioMapping1 DIO0 = TxDone (`0x40`); IRQ flags cleared before/after TX
- [x] TX timeout forces standby; `lora_set_ok(false)` — fail-soft, no hang
- [x] `lora_get_seq()` — increments after each successful TX (wraps at 65535)
- [x] Payload 1..255 bytes; bring-up beacon TX ~0.2 Hz; F8 owns mission rate scheduler
- [x] Clean build verified (2026-08-20); no packetizer or ground RX in F7.3

#### F7.4 — Ground station

**Status:** complete (2026-08-20)

- [x] Modem match sheet in `ground/README.md` (915 MHz SF8/BW125/CR4/5, sync `0x12`, preamble 8)
- [x] `packet.h` — 28-byte v1 layout, big-endian, CRC-16/CCITT-FALSE over bytes 0–25
- [x] `packet_v1_pack` / `packet_v1_unpack` / `packet_crc16` (header-only; F8 packetizer reuses)
- [x] Host `test_packet_v1` (pack, unpack round-trip, corrupt/version fail; minimal CRC golden `0x18EF`; manual run pending)
- [x] `ground/decode_packet` CLI — hex payload decode + RSSI/SNR log (`n/a` if omitted)
- [x] Clean build verified (2026-08-20); F7.4 itself had no `app_run` TX (bring-up beacon added later; F8 owns mission rate)

### 12.3 Proposed packet v1 (freeze as team Q16)

| Offset | Len | Field |
|---|---|---|
| 0 | 1 | `version = 0x01` |
| 1 | 1 | `mission_state` |
| 2 | 2 | `seq` |
| 4 | 4 | `time_ms` |
| 8 | 4 | `lat_e7` |
| 12 | 4 | `lon_e7` |
| 16 | 2 | `gps_alt_m` |
| 18 | 2 | `baro_alt_m` |
| 20 | 2 | `temp_c_x100` |
| 22 | 2 | `batt = 0xFFFF` (N/A) |
| 24 | 1 | `flags` |
| 25 | 1 | `sats` |
| 26 | 2 | `crc16` |

### 12.4 Verification / exit criteria

**Software verification (tick when work packages land):**

- [x] Clean build (`make clean && make` in `balloon-project-stm32mx/`) — verified 2026-08-20
- [x] Host tests for packet v1 pack / CRC16 if extracted as pure logic (recommended) — `test_packet_v1` authored; manual run pending
- [x] TX fail path does not hang MCU — timeout on DIO0 wait; fail-soft health (F7.3 code-path verified)

**Hardware exit (pending bench — tick when §21 F7 procedure passes):**

- [ ] Bench: RX node receives packets with increasing `seq`
- [ ] CRC validated on ground
- [ ] TX rate limited (e.g. ≤0.5 Hz) during test
- [ ] Second RFM95W + Nucleo (or equiv.) for RX available (ops Q20)

---

## 13. Phase F8 — Mission state machine and packetizer

**Phase status:** software-complete (F8.1–F8.4, 2026-09-05); HW exit open (§13.3 / §21).

### 13.0 Objective

Autonomous flight behavior and unified telemetry packing.

### 13.1 Entry criteria

- [x] F3 and/or F5 software-complete (altitude API available) — F3 `baro_read` / F5 GPS APIs
- [x] F7 software-complete for live TX (state machine host-testable without radio) — 2026-08-20

### 13.1.1 Pre-F8 audit (docs only — 2026-08-22; F6 updated 2026-08-24; cleanup 2026-09-05)

F8 coding may start per §4 / §13.1. Soft spots cleared or frozen in rev 0.39:

- **F6 software-complete** (2026-08-24 audit remediation); HW exit still §21.
- Packet `flags` polarity **frozen**: wire byte bit set = healthy (OK); `flags = (uint8_t)(~error_flags_get() & 0xFFu)` — documented in `packet.h` and `ground/README.md`.
- Doc/code drift fixed: §4 “28B packet v1”; headers/`app_run` bring-up beacon wording aligned; `BENCH=1` removed from §21 and Logic Analyzer Bench Guide (default ~5 s beacon).
- Host tests still marked pending in `tests/host/README.md`: `test_ms5611_adc`, `test_ms5611_comp`, `test_packet_v1`, `test_sdlog_name` (developer manual run).
- F1 §6.4 HW ticks vs §21 F1 open — consistency cleanup later if desired.
- Open §21 for F0/F1/F5/F6/F7 remain non-blockers for F8 coding.

### 13.2 Work packages

#### F8.1 — State enum and transitions

**Status:** complete (2026-09-05)

States: `PAD`, `ARMED`, `ASCENT`, `FLOAT`, `BURST`, `DESCENT`, `LANDED`, `BEACON` (wire 0–7 in `mission.h`)

Rules:

- [x] No mag-switch: auto ARMED after healthy altitude source + `MISSION_ARM_HOLD_MS` (10 s)
- [x] ASCENT: sustained positive altitude rate (`MISSION_ASCENT_RATE_MPS` / sustain)
- [x] FLOAT: high altitude + near-zero rate
- [x] BURST: large negative instantaneous rate and/or IMU freefall — **latched**
- [x] LANDED: altitude stable >60 s (`MISSION_LANDED_STABLE_MS`)
- [x] BEACON: entered after LANDED (LoRa rate from F8.2 schedule)
- [x] `mission.c` / `mission.h`; Makefile `C_SOURCES`; `mission_init` / `mission_update` in `app_run`
- [x] Host `test_mission_sm` (full walk + BURST latch + freefall)

#### F8.2 — Schedulers

**Status:** complete (2026-09-05)

| State | LoRa rate | Camera | Notes |
|---|---|---|---|
| ASCENT | ~0.5 Hz (2000 ms) | ~30 s | |
| FLOAT | ~0.2 Hz (5000 ms) | ~30 s | |
| DESCENT | ~0.5 Hz (2000 ms) | off (optional→off until F9) | |
| BEACON | ~1/60 s (60000 ms) | off | |
| PAD / ARMED / BURST | 2000 ms | off | Locked defaults (not in roadmap table) |
| LANDED | 60000 ms | off | Same as BEACON |

- [x] `schedule_lora_period_ms` / `schedule_camera_period_ms` + `schedule_init` / `schedule_poll`
- [x] `app_schedule_tick` replaces fixed 5 s beacon; SD log on LoRa-due; camera due → stub (`g_cam_due_count`) for F9.3
- [x] Host `test_schedule` (period table, due timing, state-change, cam-off)
- [x] Clean build with `schedule.c` in Makefile

#### F8.3 — Packetizer

**Status:** complete (2026-09-05)

- [x] Fill packet v1 from latest samples + flags — `packetizer_fill` (OK polarity flags)
- [x] CRC16 — via `packetizer_pack` → `packet_v1_pack`
- [x] `packetizer.c` / `packetizer.h`; Makefile; `app_beacon_build` samples sensors then fill
- [x] Host `test_packetizer` (field fill, temp override, fill→pack golden matching F7.4 rich vector)

#### F8.4 — Host-side state tests (recommended)

**Status:** complete (2026-09-05)

- [x] Feed simulated altitude profiles; assert state sequence — baseline in `test_mission_sm` (F8.1)
- [x] Edge profiles (F8.4): PAD no-arm / interrupted arm reset; no false ASCENT; FLOAT rate gate; short freefall; DESCENT while falling (no early LANDED)

### 13.3 Verification / exit criteria

**Software verification (tick when work packages land):**

- [x] Clean build (`make clean && make` in `balloon-project-stm32mx/`) — F8.1–F8.4 verified 2026-09-05
- [x] Host tests: simulated altitude profiles walk PAD→…→BEACON correctly — `test_mission_sm` (F8.1 + F8.4 edge profiles 2026-09-05)
- [x] BURST does not clear when descent slows (host or unit test) — `test_mission_sm` latch case
- [x] Packetizer CRC16 host-testable against golden vectors — `test_packet_v1` + `test_packetizer` fill→pack golden

**Hardware exit (pending bench — tick when §21 F8 procedure passes):**

- [ ] Live: LoRa rates match scheduler table within tolerance
- [ ] End-to-end state transitions with real sensors on hardware

---

## 14. Phase F9 — ArduCAM imaging → SD

**Phase status:** not started — software work unblocked by F1 + F6 software-complete; **blocked on ArduCAM SKU** (Gabe); HW → §21.

### 14.0 Objective

Capture flight imagery to microSD without breaking telemetry deadlines.

### 14.1 Entry criteria

- [x] F1 + F6 software-complete — F6 soft-complete 2026-08-24; still blocked on ArduCAM SKU (Gabe)
- [ ] **Gabe confirms ArduCAM SKU** (2MP Mini B0067 vs 5MP OV5642) — **hard coding blocker** for correct driver
- [ ] Interim assumption if forced: schematic Mini 2MP

### 14.2 Work packages

#### F9.1 — Sensor bring-up

- I2C ID/probe; sensor init tables for confirmed SKU
- SPI FIFO / frame read path

#### F9.2 — Capture service

- `camera_capture_to_sd(const char *path)`
- Stream in chunks; **do not** allocate full-frame RAM buffers beyond chip capacity

#### F9.3 — Mission integration

- Trigger on mission timer in ASCENT/FLOAT
- Yield SPI between chunks so LoRa/SD can run
- Respect ArduCAM thermal limits (capture earlier if cold risk)

### 14.3 Verification / exit criteria

**Software verification (tick when work packages land):**

- [ ] Clean build (`make clean && make` in `balloon-project-stm32mx/`)
- [ ] Failure sets `cam_ok = false` without reboot loop — fail-soft
- [ ] Chunked capture does not allocate full-frame RAM beyond chip capacity

**Hardware exit (pending bench — tick when §21 F9 procedure passes):**

- [ ] Valid image file opens on PC
- [ ] During capture, LoRa still meets minimum beacon rate (measure)

---

## 15. Phase F10 — APRS (DRA818V)

**Phase status:** software verification complete (2026-09-08); hardware exit open (§15.3 / §21). Full phase exit pending bench / license — see §21 F10.

### 15.0 Objective

Backup VHF position beacons.

### 15.1 Entry criteria

- [x] F5 software-complete (GPS fix API for payload encoding)
- [ ] APRS cable correct (mirrored face-to-face) — bench validation in §21
- [ ] Audio path connected (team confirmed) — bench validation in §21

**On-air blocker (not a software dry-run blocker):** amateur callsign + license (Q19) before RF TX — use `APRS_RF_ENABLE=0` until confirmed.

### 15.2 Work packages

#### F10.1 — Power and AT config

**Status:** complete (2026-09-05)

- [x] PD high (normal); PTT high (RX) idle — CubeMX USER CODE + `aprs_init`
- [x] USART2 @ 9600 8N1 (USER CODE re-init + `.ioc`); DRA818V AT baud
- [x] AT sequence: `DMOCONNECT` (≤3 retries) → `DMOSETGROUP` 144.3900 / SQ=4 → `DMOSETVOLUME=8` → `SETFILTER=1,1,1`
- [x] `aprs.c` / `aprs.h`; Makefile `C_SOURCES`; `(void)aprs_init()` fail-soft in `app_init`
- [x] `error_flags_set_aprs_ok` + `aprs_is_ok()`; host `test_aprs_at` (AT format / ACK parse)
- [x] Clean build verified (2026-09-05); **no PTT TX / no AFSK / no `APRS_RF_ENABLE`** in F10.1

#### F10.2 — AFSK generator

**Status:** complete (2026-09-08)

- [x] TIM2 CH1 (PA0) PWM → 1200/2200 Hz Bell 202 (`aprs_afsk_set_tone` / `stop` / `play_bits`)
- [x] AX.25 UI frame: dest `APZSSI`, src `N0CALL-11` (O6 placeholder), path `WIDE2-1`, info `!lat/lonO/A=feet`
- [x] Pure encode: lat/lon format, FCS, bit-stuff + NRZI bitstream; host `test_aprs_ax25`
- [x] `extern htim2`; DWT bit pacing; **PTT remains high** (no RF TX / no `APRS_RF_ENABLE`)
- [x] Clean build verified (2026-09-08); not wired into `app_run` (blocking play = bench/GDB)

#### F10.3 — PTT sequencing

**Status:** complete (2026-09-08)

- [x] Non-blocking SM: PTT lead 200 ms → AFSK bit play (DWT) → tail 50 ms → idle
- [x] `aprs_tx_start` / `aprs_poll` / `aprs_tx_busy`; `SCHEDULE_APRS_MS` 60 s all states; `aprs_due` in `schedule_poll`
- [x] App wire: due + `gps_has_fix` → start; `aprs_poll` every `app_run`; skip if busy
- [x] `APRS_RF_ENABLE` default 0 (Makefile): AFSK dry-run, PTT stays high; `=1` keys PTT (licensed only)
- [x] Host `test_schedule` APRS due; clean build verified (2026-09-08); blocking `play_bits` remains bench-only

#### F10.4 — Dry-run mode

- [x] Build flag `APRS_RF_ENABLE=0` until license confirmed (F10.3 gate; F10.4 soft-exit)
- [x] `aprs_rf_enabled()`; GDB `g_aprs_attempts` / `g_aprs_ok` / `g_aprs_fail` / `g_aprs_last_info`
- [x] Host `test_aprs_ax25` documented as no-RF frame proof; README dry-run vs RF notes
- [x] Clean build verified (2026-09-08) with default `APRS_RF_ENABLE=0`

### 15.3 Verification / exit criteria

**Software verification (tick when work packages land):**

- [x] Clean build (`make clean && make` in `balloon-project-stm32mx/`) — 2026-09-08
- [x] `APRS_RF_ENABLE=0` dry-run: AX.25 frame build host-testable or logged without RF (`test_aprs_ax25` + `g_aprs_last_info`)
- [x] PTT sequencing does not block mission loop (F10.3 — `aprs_poll` catch-up ≤ 32 bits/call)

**Hardware exit (pending bench — tick when §21 F10 procedure passes):**

- [ ] AT commands ACK
- [ ] Audio tones verified on scope before RF
- [ ] On-air only with license: received on APRS client / HT

---

## 16. Phase F11 — System integration (HIL)

### 16.0 Objective

Prove combined stack under realistic conditions.

### 16.1 Entry criteria

- [ ] Chase-critical path F0–F8 implemented
- [ ] F9/F10 as far as unblocked

### 16.2 Work packages

#### F11.1 — Full-stack soak

- ≥1 hour continuous run; SD log continuous; LoRa RX count
- Inject GPS loss / SD remove; confirm fail-soft

§21 per-subsystem bench backlog does **not** satisfy F11 — F11 is full-stack HIL on hardware.

#### F11.2 — RF range smoke test

- Ground LOS range check (not full 100 km claim)

#### F11.3 — Cold / freezer test (ops + firmware)

- Watch crystal UART, SD writes, brown-out behavior
- Document failures

#### F11.4 — Defect burn-down

- Fix P0/P1 bugs only for flight; defer cosmetics

### 16.3 Exit criteria

- [ ] Written HIL report: pass/fail per subsystem
- [ ] No open critical defects on GPS, SD, LoRa, mission SM

---

## 17. Phase F12 — Flight readiness and software freeze

### 17.0 Objective

Ship a known binary to the pad.

### 17.1 Checklist

- [ ] Firmware version tagged (e.g. `flight-YYYYMMDD-vX.Y`)
- [ ] Packet + LoRa params documented and matched on ground RX
- [ ] Callsign programmed if APRS enabled
- [ ] SD card formatted/empty with known good card
- [ ] Boot shows expected `*_ok` flags on pad (GPS may wait for sky)
- [ ] Go/No-Go: chase-critical path green

### 17.2 Exit criteria

- [ ] Tagged release binary archived
- [ ] Ground station checklist signed
- [ ] Rollback plan: previous tag kept

---

## 18. Open items and external dependencies

| ID | Item | Owner | Blocks |
|---|---|---|---|
| O1 | Exact ArduCAM SKU | Gabe (BOM) | F9 driver correctness |
| O2 | BOM confirm PT1000 | Gabe | F4 confidence |
| O3 | CubeMX `.ioc` single owner | Team | Merge conflicts |
| O4 | RadioLib vs HAL | Team — **roadmap standard = HAL** | F7 style |
| O5 | Freeze packet + SF/BW/freq | Firmware + ground | F7/F8 |
| O6 | Ham license / callsign | Ops | F10 on-air |
| O7 | Ground RX ready date | Ops | F7 validation |

---

## 19. Risk register (software)

| Risk | Mitigation |
|---|---|
| Shared SPI starvation by camera | Chunked capture; mission priority to LoRa |
| GPS baud mismatch | F0 forces 9600 |
| CubeMX regen wipes work | USER CODE only; App/ outside Core |
| APRS illegal TX | `APRS_RF_ENABLE` gate |
| Cold SD corruption | Industrial card; flush; power-loss tests |
| Scope creep | Phase gates; chase-critical path first |

---

## 20. Quick-start for a new implementer

1. Read §2 (system) and §3 (standards).  
2. Read [Firmware Development Guidelines.md](Firmware%20Development%20Guidelines.md) (verification, deferred HW, host tests).  
3. Find the lowest phase that is **not software-complete**.  
4. Confirm that phase’s **entry criteria** (software-complete of dependencies; open §21 HW items do not block coding).  
5. Implement only listed work packages.  
6. Run software verification; tick software boxes; add deferred HW items to **§21** when no board.  
7. PR title `firmware: complete Phase Fx — <name>` **only after §21 HW pass** for that phase. Software-only milestones use work-package titles (e.g. `firmware: F3.4 baro_read API`).  

**First coding task for the project:** Phase **F0**, then **F1**, then **F2** (IMU WHO_AM_I).

---

## 21. Bench verification backlog

Hardware checks deferred when no board or bench tools are available. **Tick here during bring-up week** when the flight computer PCB is powered and SWD is connected. This list does not replace **F11 system HIL** — it tracks per-subsystem bench validation.

**Clearing §21 is required for full phase exit, not for starting the next driver phase.** Software-complete of a phase unblocks the next sequential coding phase; bench items stay here until bring-up week.

**Process:** When a work package completes in software, add matching HW checks below if not already listed. Clear ticks with date and pass/fail note.

**Logic analyzer:** For SPI/UART wire-level checks on IMU, baro, temp, and GPS, flash the **default** firmware (`make clean && make`) and follow [Logic Analyzer Bench Guide.md](Logic%20Analyzer%20Bench%20Guide.md) (Captures A–C). The ~5 s bring-up beacon exercises baro/temp/SD/LoRa; IMU sample frames need GDB `imu_read` if required. GDB remains available for functional checks listed in each phase procedure below.

### F0 — Foundation

- [ ] Firmware flashes via ST-Link and reaches `while(1)` / `app_run` after reset

### F1 — SPI bus

- [ ] CS lines idle high (meter or logic analyzer on IMU/BARO/Temp/LoRa/SD CS)
- [ ] Dummy SPI transfer does not leave any CS stuck low
- [ ] Timeout path releases CS (analyzer or fault injection)

**Logic analyzer:** [Logic Analyzer Bench Guide.md](Logic%20Analyzer%20Bench%20Guide.md) Capture B with default firmware (idle CS + single-slave activity during beacon baro/temp/SD/LoRa transfers).

### F2 — IMU (ICM-42688-P)

**Checklist (tick with pass date when bench complete):**

- [x] WHO_AM_I reads `0x47` on hardware (SWD watch or debugger) — pass 2026-08-22
- [x] Post-init register read-back: `GYRO_CONFIG0` / `ACCEL_CONFIG0` = `0x08`, `PWR_MGMT0` = `0x0F` — pass 2026-08-22
- [x] After F2.3 sample read: accel/gyro values change when board is moved or tilted — pass 2026-08-22

**Bench procedure (when PCB + ST-Link available):**

1. Flash `build/balloon-project-stm32mx.elf` from default `make` (see `balloon-project-stm32mx/README.md` § SWD / flash and [Logic Analyzer Bench Guide.md](Logic%20Analyzer%20Bench%20Guide.md) Capture A).
2. Confirm `app_init` → `while(1)` / `app_run` after reset.
3. Logic analyzer: SPI on J11 + IMU_CS (TP20); WHO_AM_I MISO byte `0x47` at init; periodic `imu_read` only if called from GDB (MOSI first byte `0x9F`).
4. After `imu_init`: `imu_init()` returns true, `imu_is_ok()` true, `error_flags_imu_ok()` true; optional WHO_AM_I reg read = `0x47` (SWD/GDB).
5. Read-back via SPI/debugger: `GYRO_CONFIG0` / `ACCEL_CONFIG0` = `0x08`, `PWR_MGMT0` = `0x0F`.
6. `imu_read(&sample)` repeatedly (GDB): flat rest ~1 g on one accel axis (orientation-dependent); tilt/rotate changes ax/ay/az and gx/gy/gz; `imu_is_ok()` stays true on success.
7. Tick checklist above + §7.3 hardware exit items; add roadmap rev with bench date; update §7 phase status to `complete (bench YYYY-MM-DD)`.
8. PR title: `firmware: complete Phase F2 — IMU` (roadmap §20).

**On failure:** do not tick exit — check SPI/CS/power, IMU variant (`-V` WHO_AM_I = `0xDB`), and `PWR_MGMT0` if samples are static.

### F3 — Barometer (MS5611)

**Checklist (tick with pass date when bench complete):**

- [x] Reset + PROM read on hardware; CRC4 passes — pass 2026-08-22
- [x] After `baro_init`: `baro_init()` returns true, `baro_is_ok()` true, `error_flags_baro_ok()` true — pass 2026-08-22
- [x] After F3.2: `baro_read_raw` returns non-zero D1/D2; D1 changes directionally when board lifted ~1–2 m (raw ADC) — pass 2026-08-22
- [x] Indoor pressure plausible (~980–1040 hPa) — requires F3.4 `baro_read` on hardware — pass 2026-08-22
- [x] Altitude responds to ~1–2 m lift — requires F3.4 `baro_read` on hardware — pass 2026-08-22

**Bench procedure (when PCB + ST-Link available):**

1. Flash `build/balloon-project-stm32mx.elf` from default `make` (see README § SWD / flash and [Logic Analyzer Bench Guide.md](Logic%20Analyzer%20Bench%20Guide.md) Capture A — move CS clip to TP22).
2. Confirm `app_init` → `while(1)` / `app_run` after reset.
3. Logic analyzer: SPI on J11 + BARO_CS (TP22); PROM/ADC frames; quiet gaps during conversions normal; CS not stuck low; ~5 s beacon repeats `baro_read`.
4. After `baro_init`: `baro_init()` returns true, `baro_is_ok()` true, `error_flags_baro_ok()` true.
5. `baro_read_raw(&raw)` repeatedly (beacon or GDB): non-zero `raw.d1` / `raw.d2`; `baro_is_ok()` true; D1 changes when board lifted ~1–2 m.
6. `baro_read(&sample)` repeatedly: indoor `sample.pressure_pa / 100` ≈ 980–1040 hPa (site-dependent); `baro_is_ok()` true on success; raise board ~1–2 m and confirm `sample.alt_m` increases directionally.
7. Tick checklist above + §8.3 hardware exit items; add roadmap rev with bench date.
8. PR title: `firmware: complete Phase F3 — Barometer` (roadmap §20).

**On failure:** do not tick exit — check SPI/CS/power, `BARO_CS` (PB2), and PROM/CRC (`error_flags_baro_ok` false on CRC mismatch).

### F4 — Temperature (MAX31865 + PT1000)

**Checklist (tick with pass date when bench complete):**

- [x] After F4.1: `temp_init()` returns true, `temp_is_ok()` true, `error_flags_temp_ok()` true; CONFIG read-back `0x90` — pass 2026-08-22
- [x] After F4.2: `temp_read_raw` returns non-zero ADC; room-temp ADC/°C plausible via helpers (~15–30 °C) — pass 2026-08-22
- [x] After F4.3: `temp_read(&sample)` returns true, `temp_is_ok()` true on success path; room-temp `sample.temp_centi_c` plausible (~15–30 °C) — pass 2026-08-22
- [x] Hand on probe moves reading — requires F4.3 `temp_read` on hardware — pass 2026-08-22
- [x] Disconnect fault (if safe to test) sets fault flag — `temp_read` / `temp_read_raw` FAULT bit / Fault Status on hardware — pass 2026-08-22

**Bench procedure (when PCB + ST-Link available):**

1. Flash `build/balloon-project-stm32mx.elf` from default `make` (see README and [Logic Analyzer Bench Guide.md](Logic%20Analyzer%20Bench%20Guide.md) Capture A — move CS clip to TP21).
2. Logic analyzer: SPI on J11 + Temp_CS (TP21); CONFIG read-back `0x90` at init; ~5 s beacon: ~60 ms conversion gap then RTD burst.
3. After `temp_init`: `temp_init()` returns true, `temp_is_ok()` true, `error_flags_temp_ok()` true; optional CONFIG reg read-back = `0x90` (SWD/GDB).
4. `temp_read_raw(&raw)` repeatedly (beacon or GDB): non-zero `raw.adc`; `temp_is_ok()` true on success; room-temp °C plausible via `temp_rtd_adc_to_ohm` + `temp_pt1000_ohm_to_c`.
5. `temp_read(&sample)` repeatedly — room-temp plausible; `temp_is_ok()` true on success; hand on probe changes reading.
6. Tick checklist above + §9.3 hardware exit items; add roadmap rev with bench date.

**On failure:** do not tick exit — check SPI/CS/power, `Temp_CS` (PA8), and CONFIG read-back (`error_flags_temp_ok` false on mismatch).

### F5 — GPS (MAX-M10S)

**Checklist (tick with pass date when bench complete):**

- [ ] After F5.1: USART1 IRQ fills ring; `gps_poll()` extracts NMEA lines indoor (fix not required); `gps_copy_line()` returns sentence text
- [ ] Bytes received at 9600 on bench/outdoor
- [ ] Outdoor: valid lat/lon within expected region (requires F5.2/F5.3 parser + `gps_has_fix()`)
- [ ] Antenna connected for outdoor fix tests

**Bench procedure (when PCB + ST-Link available):**

1. Flash default firmware (`make`); confirm `app_init` → `app_run`; `gps_is_ok()` true after init (RX armed).
2. Logic analyzer: [Logic Analyzer Bench Guide.md](Logic%20Analyzer%20Bench%20Guide.md) Capture C — UART on PA10 (`GPS_TX` → MCU RX), 9600 8N1; NMEA visible; fix not required indoors.
3. Indoor (F5.1): confirm `gps_poll()` receives NMEA via `gps_copy_line()` (SWD/GDB optional).
4. After F5.2/F5.3: indoor sentences parse; `gps_has_fix()` may be false (expected).
5. Outdoor with antenna: valid lat/lon; `gps_has_fix()` true when sky visible.
6. Tick checklist above + §10.3 hardware exit items; add roadmap rev with bench date.

### F6 — microSD logging (FatFS)

**Checklist (tick with pass date when bench complete):**

- [ ] File visible on PC after flight-sim loop
- [ ] Pull-power mid-write test: document corruption mitigations (flush policy)
- [ ] Industrial microSD exercised on hardware

**Bench procedure (when PCB + ST-Link available):**

1. Insert industrial microSD (detect high = present).
2. Run flight-sim append loop; pull card; verify CSV on PC.
3. Optional: power-loss during write; document flush policy outcome.
4. Tick checklist above + §11.3 hardware exit items; add roadmap rev with bench date.

### F7 — LoRa telemetry (RFM95W)

**Checklist (tick with pass date when bench complete):**

- [ ] After `lora_init`: VERSION `0x12`, `lora_is_ok()` true, `error_flags_lora_ok()` true (SWD/GDB)
- [ ] After F7.2: OpMode LoRa+standby (`0x81`), Frf `0xE4C000`, ModemConfig1 `0x72`, ModemConfig2 `0x84`, SyncWord `0x12` (SWD/GDB or SPI read-back)
- [ ] After F7.3: GDB `lora_tx` of known buffer; DIO0 rises; `lora_get_seq()` increases; timeout path if radio/antenna missing
- [ ] Bench: RX node receives packets with increasing `seq`
- [ ] CRC validated on ground
- [ ] TX rate limited (e.g. ≤0.5 Hz) during test
- [ ] Second RFM95W + Nucleo (or equiv.) for RX available (ops Q20)

**Bench procedure (when PCB + ST-Link available):**

1. Flash firmware; confirm `app_init` → `app_run` after reset.
2. After `lora_init`: `lora_init()` returns true, `lora_is_ok()` true, `lora_get_version()` = `0x12` (SWD/GDB optional).
3. After F7.2: SPI/GDB read-back OpMode `0x81`, Frf `0xE4C000` (`0xE4`/`0xC0`/`0x00`), ModemConfig1 `0x72`, ModemConfig2 `0x84`, SyncWord `0x12`.
4. Optional logic analyzer: SPI on J11 + `LoRa_CS` (TP23); VERSION + modem config at boot; FIFO burst on each bring-up beacon TX (~5 s).
5. After F7.3: GDB `lora_tx` — DIO0 (PB12) rises; `lora_get_seq()` increments on success.
6. When F7.4 lands: match modem settings to ground RX (SF/BW/freq/sync per §12.2); TX packets; ground station logs increasing `seq`, valid CRC — **decoder ready:** feed Nucleo RX hex payload + `--rssi` / `--snr` into `ground/decode_packet` (see `ground/README.md`).
7. Tick checklist above + §12.4 hardware exit items; add roadmap rev with bench date.

### F8 — Mission state machine and packetizer

**Checklist (tick with pass date when bench complete):**

- [ ] Live: LoRa rates match scheduler table within tolerance
- [ ] End-to-end state transitions with real sensors on hardware

**Bench procedure (when chase-critical path on hardware):**

1. Run mission SM with real baro/GPS/IMU inputs.
2. Verify state transitions and LoRa rates per §13.2 scheduler.
3. Tick checklist above + §13.3 hardware exit items; add roadmap rev with bench date.

### F9 — ArduCAM imaging → SD

**Checklist (tick with pass date when bench complete):**

- [ ] Valid image file opens on PC
- [ ] During capture, LoRa still meets minimum beacon rate (measure)

**Bench procedure (when ArduCAM SKU confirmed + hardware available):**

1. Capture to SD via `camera_capture_to_sd`.
2. Verify image on PC; measure LoRa beacon rate during capture.
3. Tick checklist above + §14.3 hardware exit items; add roadmap rev with bench date.

### F10 — APRS (DRA818V)

**Checklist (tick with pass date when bench complete):**

- [ ] AT commands ACK
- [ ] Audio tones verified on scope before RF
- [ ] On-air only with license: received on APRS client / HT

**Bench procedure (when APRS hardware + license available):**

1. F10.1 dry-run (PTT stays high): confirm USART2 @ 9600 AT sequence ACK — `DMOCONNECT` → `DMOSETGROUP` 144.3900 → `DMOSETVOLUME` → `SETFILTER`; PD/PTT idle high; `aprs_is_ok()`.
2. F10.2 tones (PTT high): `aprs_afsk_set_tone(1200)` / `2200` on scope at PA0; optional `aprs_afsk_play_bits`.
3. F10.3/F10.4 with `APRS_RF_ENABLE=0`: 60 s schedule starts AFSK SM without PTT low (scope PWM only); GDB `g_aprs_last_info` / counters after a due TX. With `APRS_RF_ENABLE=1` (licensed): PTT low → tones → PTT high; then on-air decode on APRS client / HT.
4. Tick checklist above + §15.3 hardware exit items; add roadmap rev with bench date.

### Notes

- Full-stack integration remains **§16 Phase F11 (HIL)**.
- Host unit tests (scale, parse, CRC) run on developer machine — see [Firmware Development Guidelines.md](Firmware%20Development%20Guidelines.md) and `balloon-project-stm32mx/tests/host/README.md`.

---

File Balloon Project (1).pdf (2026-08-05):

# Initial Proposal

None

Here is your high-altitude weather balloon project documentation reformatted into a clean, highly scannable, and professional engineering proposal.

# 🎈 Mission To The Edge Of Space: Avionics & Flight Computer Proposal

## 📌 Mission Statement

To design, fabricate, and fly a custom embedded flight computer to ~100,000 ft (30 km) via a high-altitude weather balloon. The payload must operate autonomously for ~2 hours in near-vacuum, -60°C conditions, transmit live telemetry via LoRa, capture Earth's curvature, and safely recover via a GPS-tracked parachute.

The Ultimate Deliverable: Custom-designed avionics that flew to the edge of
space and came back.

## ️ System Architecture

The payload consists of three independent subsystems housed within a single chassis:

1. Flight Computer (Custom PCB): STM32-based core that controls the mission state machine and telemetry.
2. Imaging Module: Raspberry Pi Zero 2W + Camera, triggered externally by the Flight Computer.
3. Recovery System: Parachute assembly integrated with independent GPS trackers.

System Block Diagram

[Antenna]
│
[Battery] ──> [Power Reg] ──> [STM32 MCU] ──> [GPS (UART)] │ ├─> [IMU (SPI)]
│ ├─> [Baro (I2C)]
│ ├─> [External Temp Probe] │ ├─> [LoRa Radio (SPI)]
│ ├─> [microSD (SPI)]
│ └─> [Camera Trigger (GPIO)]
▼

[Status LEDs]

Note: The Pi Zero camera runs its own OS independently; the Flight Computer simply toggles a GPIO pin every N seconds to capture a photo.

## ️ Hardware Design (EE Work)

Specifications: Custom 4-layer PCB, ~75×50 mm.

Layer Stackup: Signal — Ground — Power — Signal (Solid ground plane required for clean RF return paths).

Component Selection

Component | Part Number | Engineering Justification
MCU | STM32F411CEU6 | Cortex-M4 with FPU, abundant peripherals, excellent documentation.
GPS | u-blox MAX-M10S | Critical: Supports >18 km altitude. Standard GPS locks out at ~60k ft due to COCOM export limits.
Radio | RFM95W LoRa (915 MHz) | Long-range, low-power, operates on license-free US ISM band.
IMU | ICM-42688-P | Ultra-low noise gyro/accelerometer for reliable attitude logging during float.
Barometer | BMP390 | Validated for high-altitude profiles and wide temperature swings.

Ext. Temp | TMP117 | External digital probe to accurately capture ambient air temperature.
Storage | SanDisk Industrial 32GB | Industrial grade; rated for wide operating temperatures (-40°C to 85°C).
Power | 4× Samsung INR18650-35E | 2S2P configuration. Lithium-ion chemistry holds voltage at -30°C far better than LiPo.
Regulator | TPS63070 Buck-Boost | Dynamic 3.3V regulation as cell voltages drop rapidly in extreme cold.
ESD Protection | TVS Diodes | Placed on GPS, RF, and USB lines to survive static buildup on antennas.

💡 Key Design Decisions to Defend in Interviews
- $\lambda/4$ Monopole LoRa Antenna: Measures exactly 8.2 cm at 915 MHz, paired with a dedicated PCB ground plane.
- Buck-Boost Topology: Chosen over standard buck regulators because cold-induced battery voltage sag will drop below nominal requirements.
- Industrial SD Cards: Standard consumer microSD cards heavily corrupt when exposed to temperatures below 0°C.

## 💻 Firmware Architecture (Embedded Work)

Software Modules
1. HAL / Drivers: Low-level configuration for GPIO, UART, SPI, I2C, ADC, Timers, and Watchdog.
2. Sensor Layer: Drivers and data parsers for the IMU, Barometer, Temperature sensor, and GPS NMEA strings.
3. Storage: FATFS integration featuring periodic data flushes and write-after-write verification.
4. Radio: LoRa packet transmission featuring sequence numbering, CRC checks, and FEC utilizing the RadioLib library.

None

5. Telemetry Packetizer: Packs all vital sensor vectors into a fixed-size, 48-byte transmission payload.
6. Camera Trigger: Hardware GPIO toggle mapping to a strict 30-second interval during ascent.
7. Power Management: Deep-sleep routine entries during low-dynamic float states.
8. Watchdog (IWDG): Hardware watchdog to auto-recover and reboot the system from sensor brown-outs.

Mission State Machine

[ PAD ] ──> Boot, device initialization, and cold GPS lock.
│
[ ARMED ] ──> Triggered via physical button or magnetic switch.
│
[ ASCENT ] ──> Positive altitude delta detected. Telemetry TX @ 1 Hz.
│
[ FLOAT ] ──> Apogee reached. Telemetry drops to 0.2 Hz to preserve power.
│
[ BURST ] ──> Sudden descent trigger detected (>50 m/s drop).
│
[ DESCENT ] ──> Target falling. Telemetry TX updates to 0.5 Hz.
│
[ LANDED ] ──> Altitude stable for >60 seconds. Enters ultra-low power beacon mode.
│
[ BEACON ] ──> Emits GPS coordinates every 60 seconds indefinitely for recovery.

Firmware Elevator Pitch: "A real-time state machine driving an embedded avionics platform through a 2-hour mission in extreme environmental conditions, featuring autonomous failure-mode handling and a recoverable post-landing beacon."

## ️ Mechanical, Packaging & Logistics

Payload Enclosure & Rigging
- Chassis: 1" thick insulated foam box lined with reflective Mylar (Interior: ~6"×4"×3").

None

- Internal Layout: Flight computer secured on central standoffs. Battery pack mounted flat at the base to maintain a low center of gravity. Pi Zero lens aligned with a small acrylic optical window.
- External Elements: LoRa antenna oriented vertically on top; GPS patch antenna pointing zenith; temperature probe extended out the lateral wall.
- Recovery Hardware: 30" nylon parachute, Nomex shock cords, and low-friction swivels attached directly to the balloon neck.
- Weight Profile: < 4.0 lbs total mass. This satisfies FAA Part 101 exemptions, requiring no formal FAA certifications.

Core Logistics Procurement
- Launch Site: Central California Valley farmland. Safe distance (≥5 miles) from airports and major highways; predictable wind patterns.
- Gas Lift: ~150 cu ft cylinder of Helium (Party City or local welding supply). Lift calculated via Archimedes' principle: $\text{Payload Weight} \times 1.5\text{ positive lift}$.
- Balloon & Parachute: Kaymont 1200g latex balloon paired with a 30" nylon recovery parachute from HABstore.

## 📅 12-Week Project Timeline

💵 [W1-W3: Design & Fab] ──> ️ [W4-W6: Bring-up & Test] ──> 🚀 [W7-W10: Integration & Test Launch] ──> ️ [W11-W12: Main Mission]

Phase 1: Design & Fabrication
- Week 1: Assign roles (PCB, Firmware, Ops). Start KiCad schematics. Order STM32 Nucleo-F411 dev board. Read FAA Part 101 rules.
- Week 2: Complete schematics and clear Electrical Rules Check (ERC). Cross-verify Bill of Materials (BOM). Begin layout. Initialize basic UART/LED blinking on the Nucleo board.
- Week 3: Complete 4-layer PCB layout. Export Gerbers and clear Design Rules Check (DRC). Submit to JLCPCB by Wednesday. Firmware lead completes IMU and Barometer test drivers.

Phase 2: Bring-Up & Local Testing
- Week 4: Commercial parts arrive. Complete GPS NMEA parser and baseline LoRa TX code. Conduct a 5-mile ground-range line-of-sight radio test.
- Week 5: PCB arrives. Hand-assemble via hot-plate reflow. Perform initial power-on and peripheral verification. Note: Expecting 1 bodge wire / firmware workaround.
- Week 6: Go/No-Go Board Respin Decision. If unrecoverable, order a revised board Monday (8-day turnaround). If clear, port firmware from Nucleo to the custom PCB. Begin environmental freezer tests (-15°C).

Phase 3: Integration & Test Flights
- Week 7: Finalize state machine integration. Test Pi Zero camera triggers. Validate SD card write resiliency by abruptly pulling power during active logs.
- Week 8: Conduct an 24-hour continuous cold soak. Build the physical Mylar foam enclosure, perform a final mass check (< 4 lbs), and finalize launch permissions.
- Week 9: Test Launch (Low Altitude). Launch a scaled-down 300g balloon to ~25 km. This low-risk flight validates telemetry, tracking, and recovery workflows end-to-end.

Phase 4: Main Flight Operations & Closeout
- Week 10: Process test flight feedback. File formal FAA NOTAM (Notice to Air Missions). Track daily trajectory predictions via predict.sondehub.org.
- Week 11: 🚀 MAIN LAUNCH WINDOW. Deploy the 1200g balloon to 100k+ ft. Mobilize two chase vehicles tracking real-time LoRa telemetry to recover the downrange payload.
- Week 12: Process sensor logs, create altitude/temperature telemetry plots, compile curvature photos into a technical report, and open-source the project repository on GitHub.

## ⚠️ Risk Mitigation Matrix

Identified Risk | Probability | Proactive Mitigation Strategy
PCB Respin Required | High (~70%) | Buffer built into Week 6. Firmware runs concurrently on generic Nucleo dev hardware to avoid losing time.
Total Loss of Payload | Moderate (~20%) | Conduct a low-altitude test flight first. Implement redundant tracking systems (LoRa + standalone Iridium satellite backup).
Cold-Induced System Crash | Moderate | Environmental torture testing via dry-ice/freezer cycles prior to final assembly.
GPS Altitude Lock Failure | Low | Explicitly selected the u-blox MAX-M10S to bypass standard civilian COCOM limits.

Battery
Depletion
Low | Implemented cold-hardy Lithium-ion 18650 cylindrical cells encased in insulated thermal foam.

## 💰 Budget Breakdown

Budget Item Description | Minimum Flight Cost | Recommended "Moonshot" Flight Cost
Custom PCB Fabrication + Components (2 Flight Boards) | $220 | $220
Kaymont 1200g Latex Balloon | $100 | $100
Helium Gas Fill (~150 cu ft) | $90 | $90
Parachute, Nomex Shock Cord, & Rigging Lines | $40 | $40
Raspberry Pi Zero 2W + Camera Module | $40 | $40
u-blox MAX-M10S GPS Module | $35 | $35
LoRa RF Modules + Antennas (x2 for Flight + Base Station) | $30 | $30

18650 Batteries + High-Retention Holder | $30 | $30
Insulated Payload Structural Materials | $25 | $25
STM32 Nucleo Development Board | $25 | $25
Incidentals (Tape, Connectors, Helium Tank Deposit) | $50 | $50
RockBLOCK 9603 Iridium SBD Satellite Tracker (Stretch) | — | $260
Test Flight Consumables (300g Balloon + Helium) (Stretch) | — | $90
TOTAL PROJECT INVESTMENT | ~$775 | ~$1,035

📌 Funding Ask Strategy: A tight $500 bare-minimum budget allows for a single high-risk flight with zero safety buffers. The optimal funding request is $800 to ensure high recovery confidence through an initial test launch and secondary satellite tracking.

## 💼 Why This Secures Engineering Internships

- Mixed-Signal PCB Design with RF: Demonstrates an understanding of impedance matching, ground planes, and high-frequency routing—skills highly valued by hardware teams.
- Ruggedized Embedded Firmware: Proves you can write production-ready code that handles harsh environments, unexpected power drops, and state management.

- The Ultimate Talking Point: "My custom hardware survived a -60°C near-vacuum environment at 30 km altitude." It mimics NASA-aligned workflows and proves you can take a complex engineering project from schematic to flight.

## [IMPORTANT] Initial Revisions ft. Gemini

This is already an exceptionally strong proposal. It reads like a capstone project or a professional aerospace prototype. However, if you are presenting this to a review board for funding, or using it to impress an interviewer, there are a few technical vulnerabilities, logistical realities, and firmware edge cases you should tweak.]

Here are the specific optimizations I would make across your design:

### 1. Hardware & Electrical Tweaks

- The Battery Chemistry Choice: You noted that Lithium-ion (18650) holds voltage better than LiPo. While true compared to some cheap LiPos, standard Li-ion chemistries still suffer massive capacity drops (up to 40–50%) and voltage sag at -60°C. For aerospace applications, Lithium Iron Phosphate ($LiFePO_4$) or Lithium Manganese Dioxide ($LiMnO_2$ primary cells like Energizer Ultimate Lithiums) are the gold standards because their internal resistance doesn’t skyrocket as violently in extreme cold.
- GPS Antenna Orientation: You specified a "GPS patch antenna pointing zenith." Patch antennas require a massive, stable ground plane to function well and can lose lock if the payload spins or tilts violently (which weather balloons do during ascent and burst). Consider upgrading to a helical GPS antenna—they have an omnidirectional radiation pattern that handles payload sway much better.

### 2. Firmware & Edge Case Tweaks

- The "Burst" State Logic: Your state machine detects a burst via a sudden descent trigger ($>50\text{ m/s}$ drop). Be careful here: right at the moment of burst, the air is so thin that the payload will virtually free-fall, easily exceeding $50\text{ m/s}$. However, as it hits thicker air lower down, the parachute will slow it down significantly. Ensure your state machine doesn't get confused if the descent speed drops back below your threshold later in the flight.
- LoRa Duty Cycle & Bandwidth: You have telemetry firing at 1 Hz during ascent. Depending on your LoRa Spreading Factor (SF) and bandwidth settings (needed to achieve that 5+ mile line-of-sight range), a 48-byte payload might take several hundred milliseconds to transmit. A 1 Hz rate might violate local ISM band duty cycle regulations or saturate your airtime. I'd recommend throttling the baseline ascent telemetry to 0.25 Hz or 0.5 Hz (every 2 to 4 seconds) to ensure the transmitter doesn't overheat and you stay legally compliant.

### 3. Logistical & Budget Realities

- Helium Pricing: You budgeted $90 for 150 cu ft of Helium. Unless you have a specific hookup via a university lab, industrial Helium prices have spiked wildly over the last few years. 150 cu ft of pure lab/welding-grade Helium is more likely to run you $150 to $250 today. (Party City gas is often a Helium-Air mix and won't give you the lift you calculated via Archimedes' principle).
- The "Funding Ask" Math: Your budget total says Minimum: ~$775, but your Funding Ask paragraph says "A tight $500 bare-minimum budget..." Make sure those numbers match perfectly so a sharp-eyed interviewer or professor doesn't catch the discrepancy. Change the text to reflect that your absolute bare minimum is ~$775.

### 4. Re-shaping for the Interview (The Pitch)

- Add a "Thermal Management Strategy": In a near-vacuum, there is no air to conduct heat. Ironically, components like your buck-boost regulator and the Pi Zero can overheat if they run hard, even though the outside air is -60°C. Mentioning "Vacuum Thermal Management via internal copper thermal mass dissipation" as a design challenge you solved will absolutely blow a hardware interviewer away.

Would you like help re-writing the specific sections (like the state machine logic or the budget text) to seamlessly bake these upgrades into your original layout?

Here is the fully revised engineering proposal. The technical vulnerabilities, budget math, firmware edge cases, and thermal challenges have been seamlessly integrated to make this airtight for funding boards and interviewers.

# [REDO 1] 🎈 Mission to the Edge of Space: Avionics & Flight Computer Proposal

## 📌 Mission Statement

To design, fabricate, and fly a custom embedded flight computer to ~100,000 ft (30 km) via a high-altitude weather balloon. The payload must operate autonomously for ~2 hours in near-vacuum, -60°C conditions, transmit live telemetry via LoRa, capture Earth's curvature, and safely recover via a GPS-tracked parachute.

The Ultimate Deliverable: Custom-designed avionics that flew to the edge of
space and came back.

None

## ️ System Architecture

The payload consists of three independent subsystems housed within a single chassis:

1. Flight Computer (Custom PCB): An STM32-based core that controls the mission state machine and telemetry.
2. Imaging Module: A Raspberry Pi Zero 2W + Camera, triggered externally by the Flight Computer.
3. Recovery System: A parachute assembly integrated with independent GPS trackers.

System Block Diagram
Plaintext

[Omni Antennas]
│
[Battery Pack] ──> [Power Reg] ──> [STM32 MCU] ──> [Helical GPS (UART)]
│ ├─> [IMU (SPI)]
│ ├─> [Baro (I2C)]
│ ├─> [External Temp Probe] │ ├─> [LoRa Radio (SPI)]
│ ├─> [microSD (SPI)]
│ └─> [Camera Trigger (GPIO)]
▼
[Status LEDs]

Note: The Pi Zero camera runs its own OS independently; the Flight Computer simply toggles a GPIO pin every 30 seconds to capture a photo.

## ️ Hardware Design (EE Work)

- Specifications: Custom 4-layer PCB, ~75×50 mm.
- Layer Stackup: Signal — Ground — Power — Signal (Solid ground plane required for clean RF return paths).

Component Selection

Component | Part Number | Engineering Justification

MCU | STM32F411CEU6 | Cortex-M4 with FPU, abundant peripherals, excellent documentation.
GPS | u-blox MAX-M10S | Critical: Supports >18 km altitude. Standard GPS locks out at ~60k ft due to COCOM export limits.
GPS Antenna | Helical Omni-Antenna | Replaced patch antenna to maintain satellite lock during violent payload spin/sway.
Radio | RFM95W LoRa (915 MHz) | Long-range, low-power, operates on license-free US ISM band.
IMU | ICM-42688-P | Ultra-low noise gyro/accelerometer for reliable attitude logging during float.
Barometer | BMP390 | Validated for high-altitude profiles and wide temperature swings.
Ext. Temp | TMP117 | External digital probe to accurately capture ambient air temperature.
Storage | SanDisk Industrial 32GB | Industrial grade; rated for wide operating temperatures (-40°C to 85°C).
Power | 4× Energizer L91 ($LiMnO_2$) no | Primary Lithium cells. Outperforms LiPo/Li-ion at -60°C with negligible internal resistance spikes.

Regulator | TPS63070 Buck-Boost | Dynamic 3.3V regulation to handle low-temperature battery voltage sag.
ESD Protection | TVS Diodes | Placed on GPS, RF, and USB lines to survive static buildup on antennas.

💡 Key Design Decisions to Defend in Interviews
- Vacuum Thermal Management: In a near-vacuum, there is no air to conduct heat away from components. The PCB utilizes expanded copper planes and heavy thermal vias to sink heat away from the buck-boost regulator and the Pi Zero, turning the board itself into a thermal mass to prevent overheating.
- $\lambda/4$ Monopole LoRa Antenna: Measures exactly 8.2 cm at 915 MHz, paired with a dedicated PCB ground plane.
- Primary Lithium Chemistry ($LiMnO_2$): Chosen over standard Lithium-ion or LiPo cells because its chemistry maintains voltage stability and retains capacity down to -60°C without requiring heavy, power-hungry internal heaters.
- Industrial SD Cards: Standard consumer microSD cards heavily corrupt when exposed to temperatures below 0°C.

## 💻 Firmware Architecture (Embedded Work)

Software Modules
- HAL / Drivers: Low-level configuration for GPIO, UART, SPI, I2C, ADC, Timers, and Watchdog.
- Sensor Layer: Drivers and data parsers for the IMU, Barometer, Temperature sensor, and GPS NMEA strings.
- Storage: FATFS integration featuring periodic data flushes and write-after-write verification.
- Radio: LoRa packet transmission featuring sequence numbering, CRC checks, and FEC utilizing the RadioLib library.
- Telemetry Packetizer: Packs all vital sensor vectors into a fixed-size, 48-byte transmission payload.
- Camera Trigger: Hardware GPIO toggle mapping to a strict 30-second interval during ascent.
- Power Management: Deep-sleep routine entries during low-dynamic float states.

None

- Watchdog (IWDG): Hardware watchdog to auto-recover and reboot the system from sensor brown-outs.

Mission State Machine
Plaintext

[ PAD ] ──> Boot, device initialization, and cold GPS lock.
│
[ ARMED ] ──> Triggered via physical button or magnetic switch.
│
[ ASCENT ] ──> Positive altitude delta. Telemetry TX @ 0.5 Hz (Optimized for RF airtime regulations).
│
[ FLOAT ] ──> Apogee reached. Telemetry drops to 0.2 Hz to preserve power.
│
[ BURST ] ──> Sudden descent trigger detected (>50 m/s drop). Latches state to prevent resetting in thick air.
│
[ DESCENT ] ──> Target falling. Telemetry TX updates to 0.5 Hz.
│
[ LANDED ] ──> Altitude stable for >60 seconds. Enters ultra-low power beacon mode.
│
[ BEACON ] ──> Emits GPS coordinates every 60 seconds indefinitely for recovery.

Firmware Elevator Pitch: "A real-time state machine driving an embedded avionics platform through a 2-hour mission in extreme environmental conditions, featuring autonomous failure-mode handling, RF duty-cycle compliance, and a recoverable post-landing beacon."

## ️ Mechanical, Packaging & Logistics

Payload Enclosure & Rigging
- Chassis: 1" thick insulated foam box lined with reflective Mylar (Interior: ~6"×4"×3").
- Internal Layout: Flight computer secured on central standoffs. Battery pack mounted flat at the base to maintain a low center of gravity. Pi Zero lens aligned with a small acrylic optical window.

None

- External Elements: Omnidirectional LoRa antenna oriented vertically on top; helical GPS antenna pointing zenith; temperature probe extended out the lateral wall.
- Recovery Hardware: 30" nylon parachute, Nomex shock cords, and low-friction swivels attached directly to the balloon neck.
- Weight Profile: < 4.0 lbs total mass. This satisfies FAA Part 101 exemptions, requiring no formal FAA certifications.

Core Logistics & Procurement
- Launch Site: Central California Valley farmland. Safe distance (≥5 miles) from airports and major highways; predictable wind patterns.
- Gas Lift: ~150 cu ft cylinder of pure industrial-grade Helium (sourced via local welding supply). Lift calculated via Archimedes' principle:
$$\text{Payload Weight} \times 1.5\text{ positive lift}$$
- Balloon & Parachute: Kaymont 1200g latex balloon paired with a 30" nylon recovery parachute from HABstore.

## 📅 12-Week Project Timeline

Plaintext

💵 [W1-W3: Design & Fab] ──> ️ [W4-W6: Bring-up & Test] ──> 🚀 [W7-W10: Integration & Test Launch] ──> ️ [W11-W12: Main Mission]

Phase 1: Design & Fabrication
- Week 1: Assign roles (PCB, Firmware, Ops). Start KiCad schematics. Order STM32 Nucleo-F411 dev board. Read FAA Part 101 rules.
- Week 2: Complete schematics and clear Electrical Rules Check (ERC). Cross-verify Bill of Materials (BOM). Begin layout. Initialize basic UART/LED blinking on the Nucleo board.
- Week 3: Complete 4-layer PCB layout with dedicated internal thermal copper planes. Export Gerbers and clear Design Rules Check (DRC). Submit to JLCPCB. Firmware lead completes IMU and Barometer test drivers.

Phase 2: Bring-Up & Local Testing
- Week 4: Commercial parts arrive. Complete GPS NMEA parser and baseline LoRa TX code. Conduct a 5-mile ground-range line-of-sight radio test.
- Week 5: PCB arrives. Hand-assemble via hot-plate reflow. Perform initial power-on and peripheral verification. Note: Expecting 1 bodge wire / firmware workaround.
- Week 6: Go/No-Go Board Respin Decision. If unrecoverable, order a revised board Monday (8-day turnaround). If clear, port firmware from Nucleo to the custom PCB. Begin environmental freezer tests (-15°C).

Phase 3: Integration & Test Flights
- Week 7: Finalize state machine integration. Test Pi Zero camera triggers. Validate SD card write resiliency by abruptly pulling power during active logs.
- Week 8: Conduct an 24-hour continuous cold soak. Build the physical Mylar foam enclosure, perform a final mass check (< 4 lbs), and finalize launch permissions.
- Week 9: Test Launch (Low Altitude). Launch a scaled-down 300g balloon to ~25 km. This low-risk flight validates telemetry, tracking, and recovery workflows end-to-end.

Phase 4: Main Flight Operations & Closeout
- Week 10: Process test flight feedback. File formal FAA NOTAM (Notice to Air Missions). Track daily trajectory predictions via predict.sondehub.org.
- Week 11: 🚀 MAIN LAUNCH WINDOW. Deploy the 1200g balloon to 100k+ ft. Mobilize two chase vehicles tracking real-time LoRa telemetry to recover the downrange payload.
- Week 12: Process sensor logs, create altitude/temperature telemetry plots, compile curvature photos into a technical report, and open-source the project repository on GitHub.
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

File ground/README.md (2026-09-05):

# Ground station — packet v1 decoder (F7.4)

Software support for ops RX (second RFM95W + Nucleo). F7.4 does **not** flash Nucleo firmware; it documents modem settings and ships a host CLI to decode captured payloads.

## Modem match sheet (must match flight `lora.h` defaults)
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

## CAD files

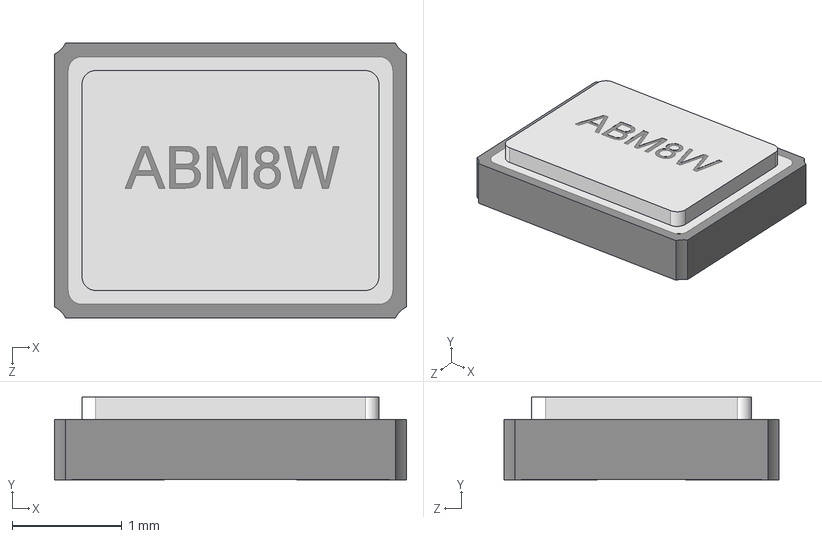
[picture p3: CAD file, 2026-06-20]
Footprint+Symbol/ABM8W-12.0000MHZ-8-K1Z-T3/ABM8W-12.0000MHZ-8-K1Z-T3.step
3.20 x 0.75 x 2.50 mm

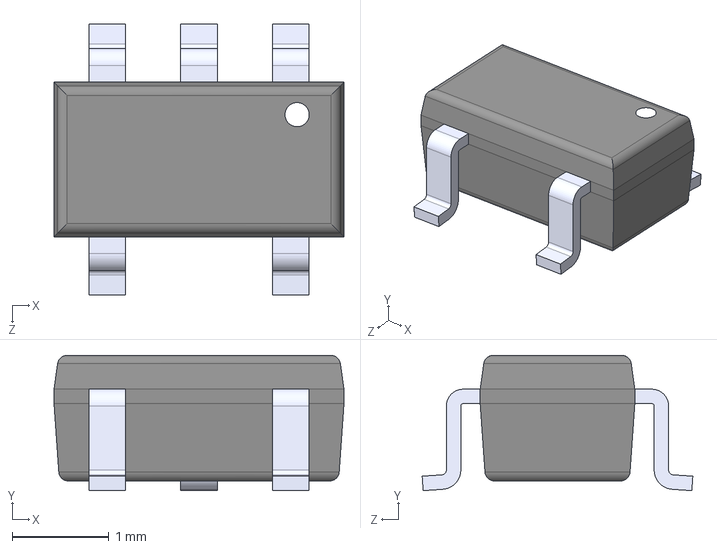
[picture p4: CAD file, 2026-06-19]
Footprint+Symbol/AP2112K-3.3TRG1/AP2112K-3.3TRG1.step
3.00 x 1.40 x 2.80 mm

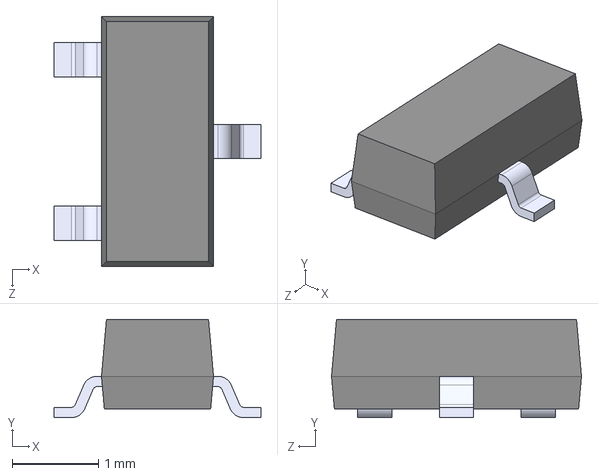
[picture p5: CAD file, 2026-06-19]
Footprint+Symbol/DMG2305UX-7/DMG2305UX-7.step
2.40 x 1.14 x 2.90 mm

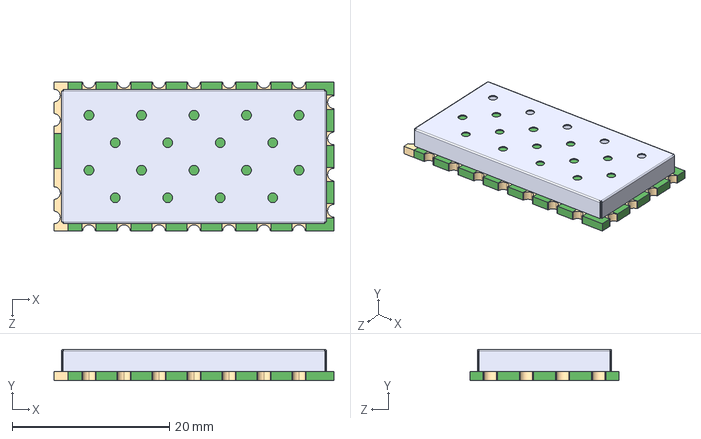
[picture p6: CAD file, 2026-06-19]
Footprint+Symbol/DRA818V/DRA818V.step
35.6 x 4.00 x 19.0 mm

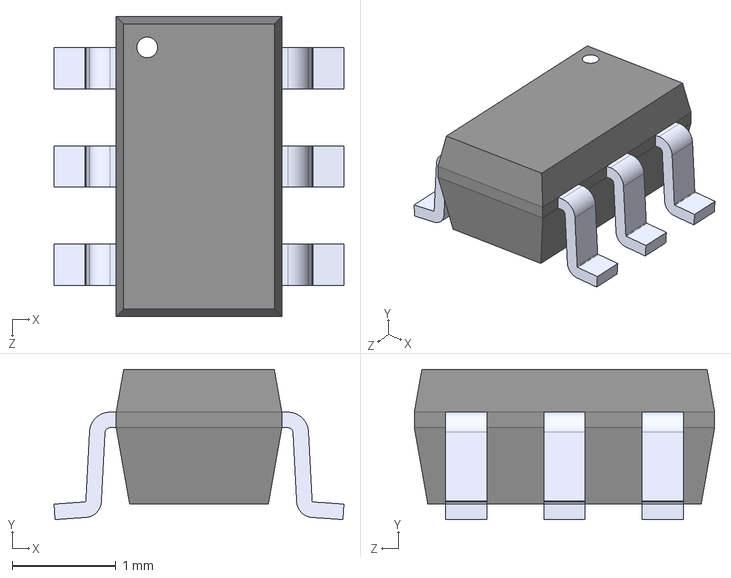
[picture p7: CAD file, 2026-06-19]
Footprint+Symbol/DW01A/DW01A.step
2.80 x 1.45 x 2.90 mm

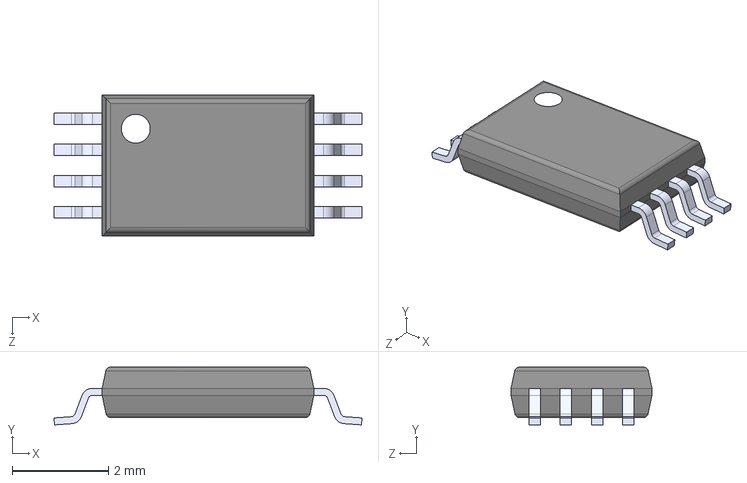
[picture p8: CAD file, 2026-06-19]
Footprint+Symbol/FS8205A/FS8205A.step
6.40 x 1.20 x 2.93 mm

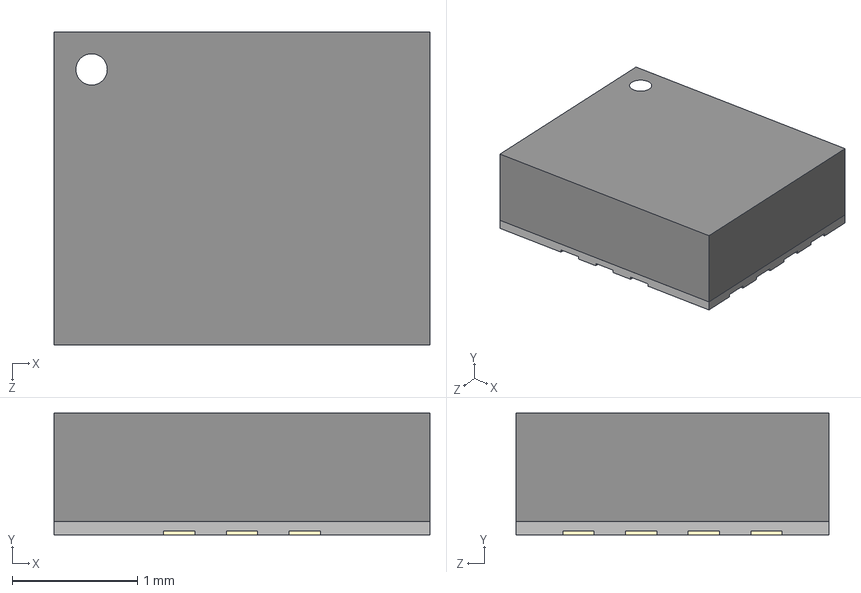
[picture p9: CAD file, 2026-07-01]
Footprint+Symbol/ICM-42688-P 2/ICM-42688-P.step
3.00 x 0.97 x 2.50 mm

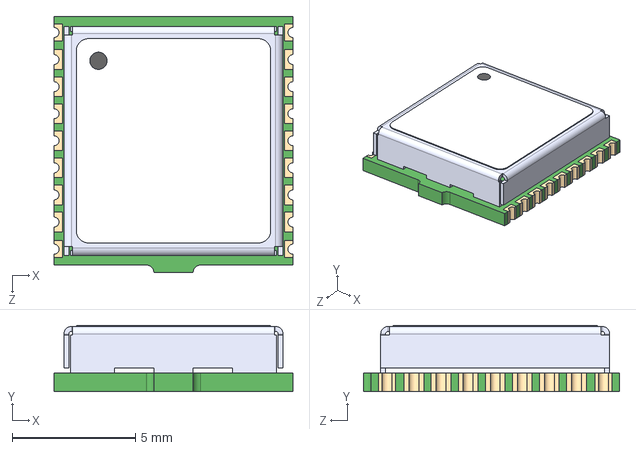
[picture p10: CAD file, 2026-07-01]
Footprint+Symbol/MAX-M10S-00B/MAX-M10S-00B.step
9.70 x 2.70 x 10.4 mm

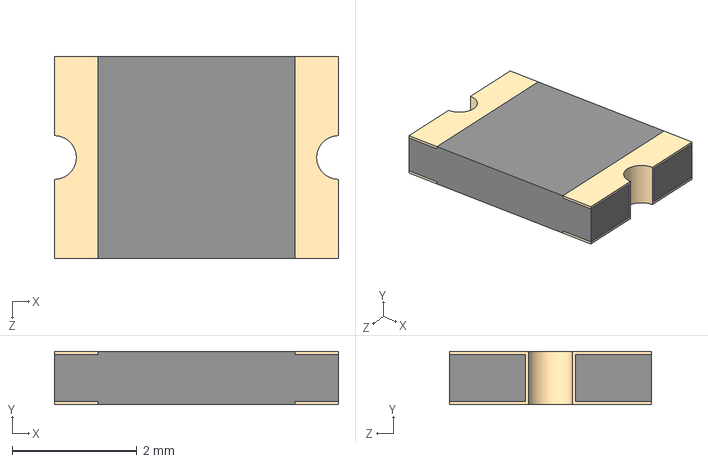
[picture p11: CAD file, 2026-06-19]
Footprint+Symbol/MF-MSMF250_16X-2/MF-MSMF250_16X-2.step
4.55 x 0.85 x 3.24 mm

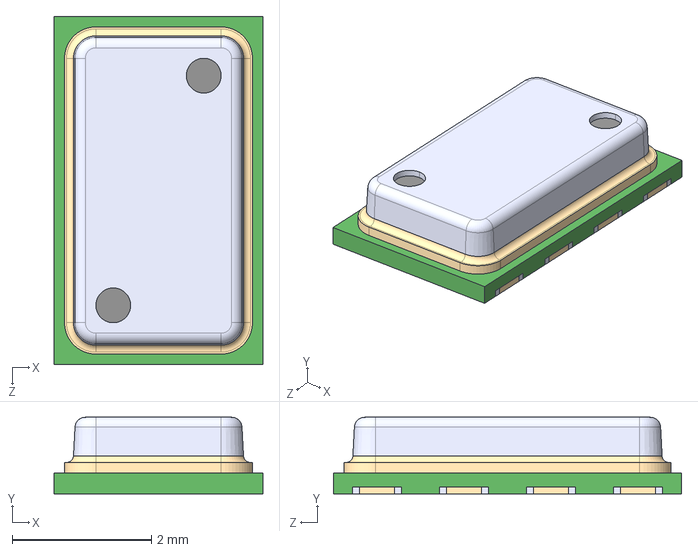
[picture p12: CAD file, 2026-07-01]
Footprint+Symbol/MS5611-01BA03/MS5611-01BA03.step
3.00 x 1.10 x 5.00 mm

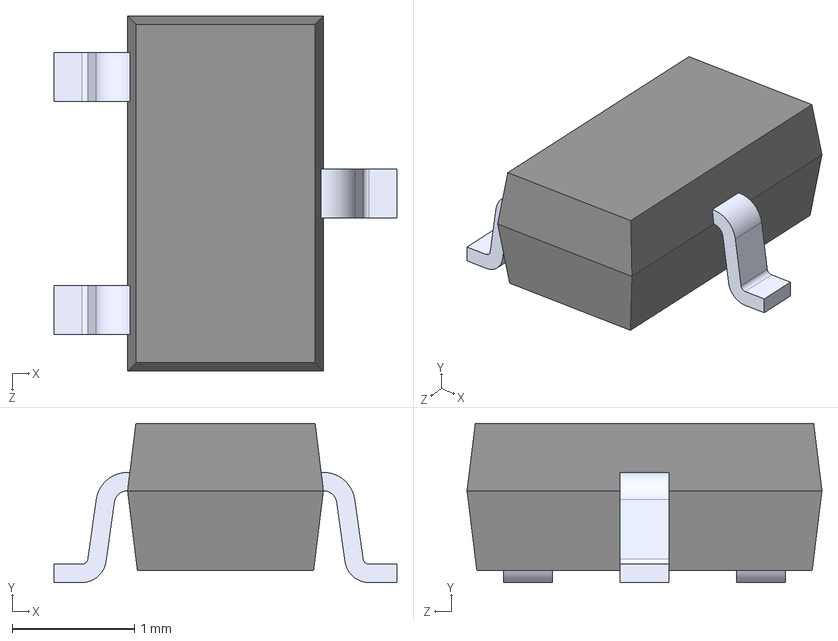
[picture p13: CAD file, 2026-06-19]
Footprint+Symbol/PMIC-XC6206P182MR_SOT23_/PMIC-XC6206P182MR_SOT23_.step
2.80 x 1.30 x 2.90 mm

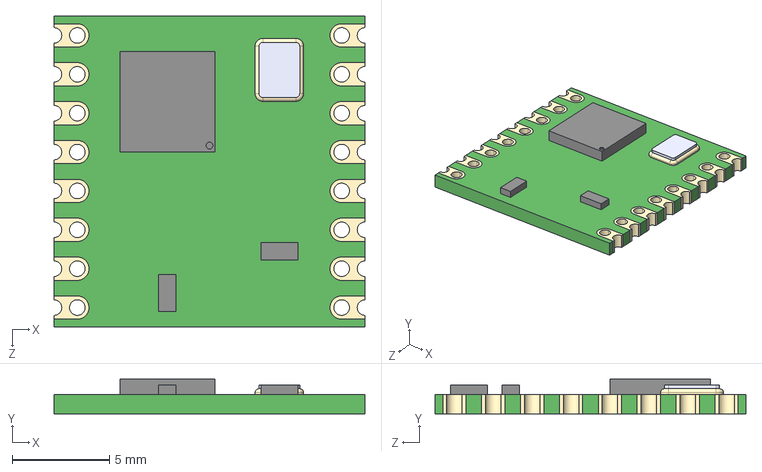
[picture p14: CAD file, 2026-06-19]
Footprint+Symbol/RFM95W-915S2/RFM95W-915S2.step
16.0 x 1.80 x 16.0 mm

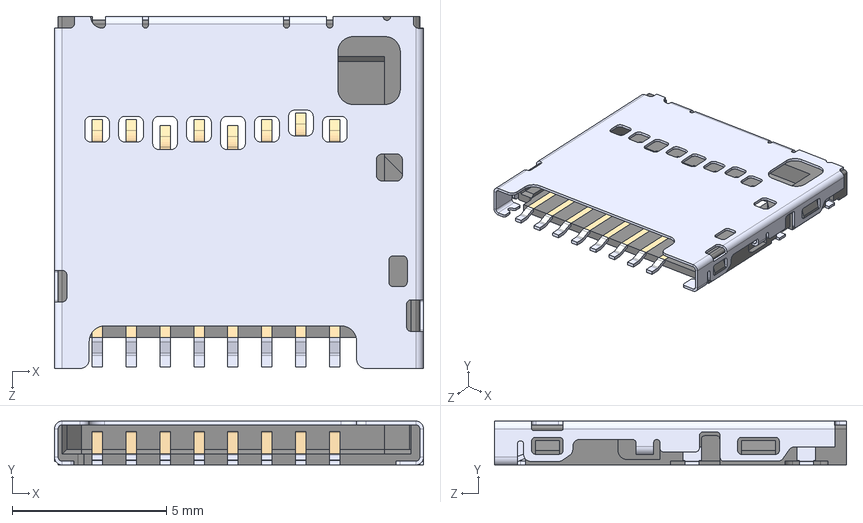
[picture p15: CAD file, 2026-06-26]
Footprint+Symbol/1040310811/1040310811.step
12.0 x 1.42 x 11.4 mm

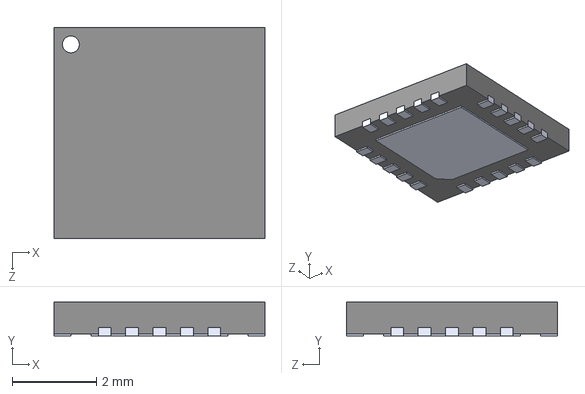
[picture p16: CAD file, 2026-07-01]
Footprint+Symbol/MAX31865ATP_T/MAX31865ATP_T.step
5.00 x 0.8 x 5.00 mm

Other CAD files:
Footprint+Symbol/TPS63070RNMR/TPS63070RNMR.step

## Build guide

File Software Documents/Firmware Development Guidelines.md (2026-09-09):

# Firmware Development Guidelines

> **Project:** SSI High-Altitude Balloon Flight Computer  
> **MCU:** STM32F411CEU6 | **Firmware tree:** `balloon-project-stm32mx/`

---

## Document control

| Field | Value |
|---|---|
| Title | Firmware Development Guidelines |
| Location | `Software Documents/Firmware Development Guidelines.md` |
| Status | Active |
| Audience | Firmware engineers, Cursor agents, reviewers |
| Related | [Main Developmental Roadmap.md](Main%20Developmental%20Roadmap.md) §3, §21; [`balloon-project-stm32mx/README.md`](../balloon-project-stm32mx/README.md); [Logic Analyzer Bench Guide.md](Logic%20Analyzer%20Bench%20Guide.md) |

### Revision history

| Rev | Date | Author | Notes |
|---|---|---|---|
| 0.1 | 2026-08-06 | Firmware | Initial guidelines: verification gates, deferred HW, host tests, bench backlog, agent policy |
| 0.2 | 2026-08-15 | Firmware | Next-phase coding unblocked rule; FAQ rows; §21 does not block F2–F7 driver work |
| 0.3 | 2026-08-15 | Firmware | F4.1 host-test note (SPI config = bench); F4.2 CVD host-test target |
| 0.4 | 2026-08-15 | Firmware | F4.2 `test_max31865_cvd` authored (manual run pending) |
| 0.5 | 2026-08-15 | Firmware | F4.2 CVD inverse root fix; `test_max31865_cvd` manual pass |
| 0.6 | 2026-08-15 | Firmware | F4.3 `temp_sample_from_raw` in `test_max31865_cvd`; `temp_read` on bench only |
| 0.7 | 2026-08-15 | Firmware | F4.3 host test manual pass |
| 0.8 | 2026-08-19 | Firmware | F5.1 `test_gps_rx` authored (ring + LF line extract; manual run pending) |
| 0.9 | 2026-08-19 | Firmware | F5.1 `test_gps_rx` manual pass (test harness fix: sequential drain, wrap trailing line) |
| 0.10 | 2026-08-19 | Firmware | F5.2 `test_gps_nmea` authored (GGA/RMC parse; manual pass 2026-08-19) |
| 0.11 | 2026-08-19 | Firmware | F5.3 `gps_sample_has_fix` / `gps_has_fix`; `test_gps_nmea` fix-validity vectors (manual pass 2026-08-19) |
| 0.12 | 2026-08-19 | Firmware | Logic analyzer bench: `make BENCH=1` / `APP_BENCH_BUS_EXERCISE`; [Logic Analyzer Bench Guide.md](Logic%20Analyzer%20Bench%20Guide.md) |
| 0.13 | 2026-08-20 | Firmware | F7.1 SX1276 VERSION probe — bench only (SPI/GPIO; no host test) |
| 0.14 | 2026-08-20 | Firmware | F7.2 Hz → Frf (`test_lora_frf` authored); modem SPI config = bench |
| 0.15 | 2026-08-20 | Firmware | F7.3 FIFO TX + DIO0 wait — bench/GDB only (SPI/GPIO; no host test) |
| 0.16 | 2026-08-20 | Firmware | F7.4 / F7 exit: packet v1 pack/CRC16 — `test_packet_v1`; ground decode = host CLI; on-air RX = bench |
| 0.17 | 2026-08-24 | Firmware | F6 host `test_sdlog_name` (FLIGHTxxx format + next index); F6 software-complete |
| 0.18 | 2026-09-05 | Firmware | Drop `BENCH=1` FAQ; default bring-up beacon keeps SPI/LoRa/SD live (~5 s) |
| 0.19 | 2026-09-05 | Firmware | F8.1 host `test_mission_sm` (state walk + BURST latch) |
| 0.20 | 2026-09-05 | Firmware | F8.2 host `test_schedule` (LoRa/camera periods + due) |
| 0.21 | 2026-09-05 | Firmware | F8.3 host `test_packetizer` (fill + golden pack/CRC) |
| 0.22 | 2026-09-05 | Firmware | F8.4 host `test_mission_sm` edge profiles; F8 software exit confirmed |
| 0.23 | 2026-09-05 | Firmware | F10.1 host `test_aprs_at` (AT format / ACK); UART/GPIO AT path = bench |
| 0.24 | 2026-09-08 | Firmware | F10.2 host `test_aprs_ax25` (AX.25 UI / APRS position); TIM2 AFSK PWM = bench |
| 0.25 | 2026-09-08 | Firmware | F10.3 `test_schedule` APRS 60 s due; PTT/AFSK SM = bench; `APRS_RF_ENABLE` default 0 |
| 0.26 | 2026-09-08 | Firmware | F10.4 dry-run logging + soft exit; `test_aprs_ax25` host gate; RF still gated |

---

## 1. Purpose

Complement the roadmap’s phase gates with **how to verify and proceed** when hardware is not available. This document is the reference for:

- Continuing driver work without blocking on a physical board or Renode
- Where to put deferred hardware checks
- How host-side tests are written and run
- What Cursor agents should and should not do

**Coding architecture and module APIs** remain in the roadmap **§3**. This file covers **verification workflow** only.

---

## 2. Verification gates

| Gate | What it proves | Blocks next *work package*? | Blocks *phase exit / F12*? |
|---|---|---|---|
| **Build + code review** | Compiles; APIs match roadmap; fail-soft paths | Soft — usually required | Soft |
| **Host unit tests** | Pure logic (scale, endian, compensation math) | Recommended for math/protocol | Soft |
| **Bench verification** | Real SPI, pins, power, sensor physics | No for sequential driver coding | Yes for phase HW exit |
| **HIL (F11)** | Full stack on real hardware | No until F11 | **Yes** for flight readiness |

**Work package complete (software):** code merged under `App/`, Makefile updated, software verification noted, roadmap work-package checklist ticked.

**Next-phase coding unblocked:** current phase is software-complete **and** the next phase’s entry criteria are met (software-complete of listed dependencies). Bench verification does **not** block sequential driver work F2–F7.

**Phase exit complete:** all work packages done **and** hardware exit criteria cleared (or explicitly deferred to §21 with a bring-up plan).

**Flight readiness (F12):** requires F11 HIL pass on real hardware. Deferred bench items do not substitute for HIL.

---

## 3. Deferred hardware (no board yet)

It is **correct and expected** to implement F2.3, F3, F4, F5, etc. without a physical board or simulator.

When hardware is unavailable:

1. Implement the work package per roadmap §3 standards.
2. Run `make clean && make` (build gate).
3. Note software verification in the roadmap (date + pass/fail).
4. Add or update **hardware checks** in roadmap **§21 Bench verification backlog**.
5. Do **not** tick phase hardware exit criteria until the board is exercised.
6. Do **not** claim Phase F2 (or any phase) fully complete if HW exit criteria remain open — unless all work packages are done and HW is explicitly deferred in §21.
7. **Do** start the next sequential driver phase (e.g. F4 after F3 software-complete) when entry criteria are met; open §21 items are not a coding blocker for F2–F7.

This matches how F0 and F1 are already tracked: software complete, bench pending.

---

## 4. Renode and simulation

**Renode** is useful later for MCU + bus regression CI when peripheral models exist. For this project today:

- There is no drop-in ICM-42688-P, MS5611, MAX31865, or RFM95W model for this PCB.
- Building those models is a real project; it should **not** block driver implementation.
- **Do not** pause F2–F4 to set up Renode unless a team member owns peripheral models.

**Revisit Renode when:**

- The board is back and you want automated regression, or
- Someone can maintain thin SPI slave stubs (WHO_AM_I + fixed sample data) shared across sensors.

No Renode install guide lives in this repo — avoids stale tooling docs. Link external Renode docs when models are added.

---

## 5. Host-side unit tests

### 5.1 Split driver code

| Layer | Examples | Testable without hardware? |
|---|---|---|
| **SPI / HAL glue** | `spi_bus_transfer`, register read/write in `imu.c` | No — needs bench or model |
| **Pure conversion** | LSB→SI scale, endian pack/unpack, MS5611 PROM math, NMEA parse | **Yes** — host `gcc` |

Prefer extracting or isolating pure functions so they can be tested on the developer machine (macOS/Linux) without STM32 HAL.

### 5.2 Location

Host tests live under:

```text
balloon-project-stm32mx/tests/host/
```

See [`balloon-project-stm32mx/tests/host/README.md`](../balloon-project-stm32mx/tests/host/README.md) for run instructions when a harness exists.

### 5.3 What to test first (examples)

| Phase | Good host-test targets |
|---|---|
| F2.3 | Accel/gyro raw → SI scale at ±16 g / ±2000 dps — `test_imu_scale` verified pass 2026-08-09 (manual) |
| F3.1 | MS5611 PROM CRC4 — `test_ms5611_crc` verified pass 2026-08-09 (manual; AN520 vector) |
| F3.2 | MS5611 24-bit ADC big-endian unpack — `test_ms5611_adc` (manual run pending) |
| F3.3 | MS5611 compensation from known PROM + ADC values — `test_ms5611_comp` (manual run pending; datasheet B3) |
| F3.4 | `baro_sample_from_raw` composition (compensate + ISA) in `test_ms5611_comp`; `baro_read` on bench only |
| F4.1 | MAX31865 CONFIG write/read-back — bench only (SPI glue; no host test) |
| F4.2 | PT1000 resistance → °C (Callendar–Van Dusen) — `test_max31865_cvd` verified pass 2026-08-15 (manual) |
| F4.3 | `temp_sample_from_raw` composition in `test_max31865_cvd`; `temp_read` on bench only — verified pass 2026-08-15 (manual) |
| F5.1 | USART RX ring + LF line extract — `test_gps_rx` verified pass 2026-08-19 (manual) |
| F5.2 | NMEA GGA/RMC parse, `lat_e7`/`lon_e7`/alt/sats — `test_gps_nmea` verified pass 2026-08-19 (manual) |
| F5.3 | `gps_sample_has_fix` / `gps_has_fix` from GGA quality + RMC status — `test_gps_nmea` fix-validity vectors verified pass 2026-08-19 (manual) |
| F6.2 | `FLIGHT%03u.CSV` format + next free index — `test_sdlog_name` (authored; manual run pending); FatFs/SPI SD = bench |
| F7.1 | SX1276 VERSION probe (`0x42`→`0x12`) — bench only (SPI/GPIO; no host test) |
| F7.2 | Hz → Frf (`test_lora_frf` verified pass 2026-08-20; 915 MHz `0xE4C000`); modem SPI config = bench |
| F7.3 | FIFO TX + DIO0 wait — bench/GDB only (SPI/GPIO; no host test) |
| F7.4 / F7 exit | Packet v1 pack/CRC16 — `test_packet_v1` (authored; manual run pending); ground decode = host CLI (`ground/decode_packet`); on-air RX = bench |
| F8 | Mission SM (`test_mission_sm` F8.1 walk + F8.4 edge profiles); schedule (`test_schedule`); packetizer fill (`test_packetizer`); pack/CRC also `test_packet_v1` |
| F10.1 | AT command format + ACK `:0` parse — `test_aprs_at` (authored; manual run pending); USART2 / PD / PTT / DRA818V ACK = bench |
| F10.2 | AX.25 UI + APRS lat/lon/alt info + FCS/bit-stuff/NRZI — `test_aprs_ax25` (authored; manual run pending); TIM2 Bell 202 PWM = bench |
| F10.3 | APRS 60 s schedule due — `test_schedule` (authored; re-run after F10.3); PTT→AFSK SM / `APRS_RF_ENABLE` = bench |
| F10.4 | Dry-run soft exit — `test_aprs_ax25` host frame proof + flight `g_aprs_last_info` / counters; RF gated (`APRS_RF_ENABLE=0` default) |

---

## 6. Running tests (human / developer)

**Policy:** Cursor agents **author** tests and **document** how to run them. Agents **do not execute** host tests, HIL scripts, Renode, or flash-and-verify loops unless the user explicitly asks in that message.

When a harness exists, the developer runs tests manually:

```bash
cd balloon-project-stm32mx/tests/host
# Exact command documented in tests/host/README.md (e.g. make, or ./run_tests.sh)
```

After adding or changing tests, the agent must tell you the exact command to run and where it is documented.

**Firmware build** (always safe for agents and humans):

```bash
cd balloon-project-stm32mx
make clean && make
```

**Flash** (human or explicit user request only): see `balloon-project-stm32mx/README.md` § SWD / flash.

---

## 7. Bench verification backlog

All deferred hardware checks are tracked in one place:

**[Main Developmental Roadmap.md §21 — Bench verification backlog](Main%20Developmental%20Roadmap.md#21-bench-verification-backlog)**

After each sensor or subsystem work package:

1. Add the hardware checks needed to validate that work (WHO_AM_I, register read-back, motion, pressure range, etc.).
2. Clear ticks during **bring-up week** when the board is available.
3. Clearing §21 is required for **full phase exit**, not for starting the next driver phase.
4. F11 (system HIL) remains the full-stack gate — §21 is per-subsystem bench, not a substitute for F11.

---

## 8. Cursor agent expectations

When implementing firmware in this repo:

1. Follow roadmap **§3** (architecture, APIs, fail-operational).
2. Follow **this document** for verification and blocking rules.
3. Continue work packages without inventing Renode or “need hardware first” blockers.
4. Update roadmap work-package checklists and §21 when completing software.
5. Write host tests for pure logic when practical; document run commands in `tests/host/README.md`.
6. **Do not** run host unit tests, Renode, HIL, or flash verification unless the user explicitly requests it in that message.
7. After adding tests, provide the user the exact manual run command.

Project rules in `.cursor/rules/` reinforce these points for every session.

---

## 9. Quick reference

| Question | Answer |
|---|---|
| Can I code F2.3 without a board? | Yes |
| Can I tick F2 HW exit without a board? | No — use §21 backlog |
| Can I start F4 after F3 software-complete with F3 HW still open? | Yes |
| Can I start F11 without a board? | No |
| What does “F1 complete” mean in F4 entry? | F1 software-complete |
| When is bring-up week? | When PCB + ST-LINK are available; tick §21 then |
| Can I claim F12 without F11? | No |
| Should I set up Renode now? | No — defer unless models are owned |
| Who runs tests? | Developer manually; not the agent by default |
| Where is deferred HW tracked? | Roadmap §21 |
| How do I get live SPI for a logic analyzer? | Default `make` in `balloon-project-stm32mx/` — F8.2 schedule exercises baro/temp/SD/LoRa (~2 s on PAD; see `schedule.h`). IMU also polled in `app_run` for freefall. See [Logic Analyzer Bench Guide.md](Logic%20Analyzer%20Bench%20Guide.md). There is no `BENCH=1` flag. |

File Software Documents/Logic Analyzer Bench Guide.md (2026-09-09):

# Logic Analyzer Bench Guide

> **Project:** SSI High-Altitude Balloon Flight Computer  
> **MCU:** STM32F411CEU6 | **Firmware:** `balloon-project-stm32mx/`

---

## Document control

| Field | Value |
|---|---|
| Title | Logic Analyzer Bench Guide |
| Location | `Software Documents/Logic Analyzer Bench Guide.md` |
| Status | Active |
| Audience | Bench testers, firmware engineers |
| Related | [Main Developmental Roadmap.md](Main%20Developmental%20Roadmap.md) §21; [Firmware Development Guidelines.md](Firmware%20Development%20Guidelines.md); [`balloon-project-stm32mx/README.md`](../balloon-project-stm32mx/README.md) |

### Revision history

| Rev | Date | Author | Notes |
|---|---|---|---|
| 0.1 | 2026-08-19 | Firmware | First branch: IMU, baro, temp (SPI), GPS (UART); `make BENCH=1` |
| 0.2 | 2026-09-05 | Firmware | Drop `BENCH=1`; default build uses ~5 s bring-up beacon (baro/temp/SD/LoRa) |
| 0.3 | 2026-09-05 | Firmware | F8.2: LoRa/SD period is mission-state-dependent (`schedule.h`) |

---

## 1. Purpose

This guide explains how to use a **logic analyzer** to verify bus wiring and live traffic for the sensors that are **software-complete today**:

| Device | Bus | In this guide |
|---|---|---|
| ICM-42688-P IMU | SPI1 | Yes (init traffic; sample via GDB if needed) |
| MS5611 barometer | SPI1 | Yes |
| MAX31865 + PT1000 | SPI1 | Yes |
| MAX-M10S GPS | USART1 (UART) | Yes |
| RFM95W LoRa | SPI1 | F7–F8.2: init + state-scheduled TX (`schedule.h`); packet v1 in `packet.h` |
| microSD | SPI1 | F6: `sdlog` + `sd_spi`; CS low in short protocol bursts |
| ArduCAM | SPI1 + I2C1 | Not yet (F9) |
| DRA818V APRS | USART2 + TIM2 PWM + PTT | F10.1 AT; F10.2 AFSK; F10.3 60 s SM; F10.4 dry-run (`APRS_RF_ENABLE=0` → no PTT low; GDB `g_aprs_last_info`) |

This is **bench bring-up** with the flight `app_run` loop (mission SM + F8.2 scheduler). SPI/LoRa/SD stay active after boot on the LoRa-due schedule.

---

## 2. SPI vs UART (read this first)

**SPI sensors (IMU, baro, temp)** use four wires on a **shared** bus:

| Wire | MCU pin | Probe point | Role |
|---|---|---|---|
| SCLK | PA5 | **J11** | Clock |
| MOSI | PA7 | **J11** | MCU → sensor |
| MISO | PA6 | **J11** | Sensor → MCU |
| CS (per slave) | see below | Test pads | Chip select, **active low** |

All three SPI sensors share SCLK/MOSI/MISO. Only **one** CS line goes low per transfer.

| CS net | MCU pin | Test pad |
|---|---|---|
| `IMU_CS` | PB0 | TP20 |
| `BARO_CS` | PB2 | TP22 |
| `Temp_CS` | PA8 | TP21 |
| `LoRa_CS` | PB1 | TP23 (init SPI at boot; FIFO burst on each beacon TX) |
| `microSD_CS` | PB3 | TP24 (transaction bursts during FatFs; idle high between ops) |
| `Cam_CS` | PA4 | (idle — no driver) |

**GPS uses UART, not SPI.** There is no CS, MOSI, MISO, or SCLK on the GPS link. Clip the UART line and use an **async serial / UART** decoder.

| Signal | MCU pin | Net name | Role |
|---|---|---|---|
| MCU RX | PA10 | `GPS_TX` (module TXD) | GPS → MCU (NMEA stream) |
| MCU TX | PA9 | `GPS_RX` (module RXD) | MCU → GPS (idle in bench firmware) |

Settings: **9600 baud, 8N1**.

---

## 3. Firmware build for analyzer captures

**Default build** (no special flags):

```bash
cd balloon-project-stm32mx
make clean && make
```

Flash `build/balloon-project-stm32mx.elf` or `.bin` per [`balloon-project-stm32mx/README.md`](../balloon-project-stm32mx/README.md) § SWD / flash.

There is **no** `make BENCH=1` flag anymore. After `app_init`, `app_run` runs the mission SM plus F8.2 **state-dependent** LoRa/SD schedule (fail-soft):

1. `gps_poll` every superloop iteration; IMU sampled for freefall; altitude refreshed ~1 Hz
2. On LoRa-due (PAD/ARMED/ASCENT/DESCENT/BURST **~2 s**; FLOAT **~5 s**; BEACON/LANDED **~60 s**): `baro_read` / `temp_read` / GPS fields, `sdlog_write_sample`, and `lora_tx` of packet v1 when LoRa is healthy
3. Camera-due in ASCENT/FLOAT (~30 s) only increments a stub counter until F9

Periods live in `App/Inc/schedule.h`.

---

## 4. Analyzer setup (all captures)

1. Connect analyzer **GND** to board GND first (TP3, TP5, TP8, or TP13).
2. Logic levels are **3.3 V**. Do not clip 5 V rails with a 3.3 V-only pod.
3. Sample rate: **≥ 8 MS/s** for SPI (~0.78 MHz clock). GPS at 9600 works at lower rates; keep 8 MS/s if SPI and UART share one capture.
4. Typical USB analyzers have **8 channels** — probe **one SPI slave at a time** (shared SCLK/MOSI/MISO + that slave’s CS).
5. Start capture, then **reset the MCU** if you want init + periodic traffic in one file.
6. Triggers: SPI on **CS falling**; GPS on UART **start bit** (line falling).

### SPI decoder settings (IMU, baro, temp)

| Setting | Value |
|---|---|
| Mode | **0** (CPOL=0, CPHA=0) |
| Bit order | MSB first |
| Word size | 8 bits |
| CS / Enable | Active **low**, assign to the CS channel you clipped |

### UART decoder settings (GPS)

| Setting | Value |
|---|---|
| Protocol | Async serial / UART (not SPI) |
| Baud | 9600 |
| Data bits | 8 |
| Parity | None |
| Stop bits | 1 |

---

## 5. Capture procedures

### Capture A — SPI + IMU (start here)

**Clip:** GND, J11 SCLK, J11 MOSI, J11 MISO, **TP20 IMU_CS**.

**Expect:**

- At boot: several CS frames (WHO_AM_I, config). WHO_AM_I read on MISO includes **`0x47`**.
- Default loop does **not** issue periodic `imu_read`; after init, IMU_CS stays high unless you call `imu_read` from GDB (first MOSI byte of a sample read is **`0x9F`** = `0x1F | 0x80`).
- When IMU SPI is active: IMU_CS falls, SCLK runs, MOSI/MISO active, IMU_CS rises. Other CS stay high.

**Then** move only the CS clip to **TP22** (baro), then **TP21** (temp). Keep SCLK/MOSI/MISO on J11; change decoder Enable to the new CS channel.

### Capture B — idle CS check (F1)

**Clip:** J11 SCLK/MOSI/MISO plus multiple CS pads (TP20/21/22; optional TP23 LoRa, TP24 SD).

**Expect:**

- During a baro/temp/LoRa/SD transfer, **only** that slave’s CS is low.
- Between schedule ticks, CS lines idle **high** (short bursts on LoRa-due: ~2 s on PAD after boot).
- CS never stuck low after a transfer ends.

### Capture C — GPS UART

**Clip:** GND, **PA10** (MCU RX / `GPS_TX`). Optional: PA9 (MCU TX — should be idle).

**Expect:**

- Idle-high UART on PA10, bit time ~104 µs.
- Repeating ASCII NMEA (`$GNGGA`, `$GNRMC`, …).
- **No** CS, **no** SCLK.
- Indoor fix not required for this capture.

---

## 6. Per-device pass criteria

### IMU (ICM-42688-P)

- CS-framed SPI on IMU_CS with clock activity at init.
- WHO_AM_I response **`0x47`** at init.
- Optional: GDB `imu_read` shows sample burst (MOSI first byte `0x9F`).

### Barometer (MS5611)

- CS-framed SPI on BARO_CS.
- MOSI shows command bytes (`0x1E` reset at init; `0x48`/`0x58` conversions; `0x00` ADC read).
- Quiet gaps with CS high during ~10 ms conversions — **normal**.
- Periodic conversion traffic on each LoRa-due (~**2 s** in PAD after boot).

### Temperature (MAX31865)

- CS-framed SPI on Temp_CS.
- CONFIG read-back **`0x90`** at init.
- About every LoRa-due (~**2 s** on PAD): long quiet gap (~60 ms conversion) then RTD data burst.

### GPS (MAX-M10S)

- Continuous UART on PA10 at 9600 8N1.
- NMEA sentences visible in decoder. Fix optional indoors.

---

## 7. Fail signatures (quick debug)

| Symptom | Likely cause |
|---|---|
| SCLK runs but MISO stuck | Wiring, wrong CS, slave not powered, or probe on wrong net |
| CS low and stuck | Short, or `spi_bus_transfer` fault — check F1 |
| Activity on wrong CS | Clip error or shorted CS lines |
| GPS line idle forever | Wrong pin (TX vs RX), baud mismatch, module unpowered |
| SPI quiet after boot (no schedule bursts) | Scheduler not running, or LoRa/baro/temp all fail-soft before transfer — check `app_run` / health flags |

---

## 8. Explicitly not this branch

- **LoRa:** F7–F8.2 — `lora_init` at boot; `schedule_poll` drives `lora_tx` by mission state (~2 s on PAD). DIO0 (PB12) polled for TxDone. Packet v1 in `packet.h`; ground decode via `ground/decode_packet`.
- **microSD:** F6 — `sdlog_write_sample` on each LoRa-due; `microSD_CS` low only for each SD SPI frame. Analyzer: short CS-low bursts, not stuck low.
- **ArduCAM:** CS idle high; no driver traffic (F9).
- **APRS USART2 / PTT / PWM:** F10.1 boot AT @ 9600; F10.2/F10.3 TIM2 CH1 AFSK via SM (`aprs_poll`). Default `APRS_RF_ENABLE=0`: periodic AFSK without PTT low; inspect `g_aprs_last_info` / `g_aprs_ok` under GDB (F10.4). `APRS_RF_ENABLE=1`: PTT low during lead/play/tail (licensed RF only).
- **I2C1 (ArduCAM):** Bus idle after init.

---

## 9. Clearing roadmap §21

Logic analyzer captures support **hardware exit** checklists in roadmap §21 F1–F5. After captures pass, also confirm driver health via SWD/GDB where the §21 procedure requires (`imu_is_ok`, plausible sensor values, etc.). Tick §21 items with date and pass/fail — do not tick from analyzer alone if functional checks fail.

See [Main Developmental Roadmap.md §21](Main%20Developmental%20Roadmap.md#21-bench-verification-backlog).

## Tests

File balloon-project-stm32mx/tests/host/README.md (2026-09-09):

# Host unit tests

Host-side tests for **pure firmware logic** that does not need STM32 HAL, SPI, or a physical board.

Examples: IMU LSB→SI scale, MS5611 compensation math, NMEA parsing, telemetry packet CRC/endian packing.

## Status

**Harness active** — `test_imu_scale` (F2.3), `test_ms5611_crc` (F3.1), `test_ms5611_adc` (F3.2), `test_ms5611_comp` (F3.3 compensation + ISA + F3.4 `baro_sample_from_raw`), `test_max31865_cvd` (F4.2 RTD unpack + CVD + F4.3 `temp_sample_from_raw`), `test_gps_rx` (F5.1 ring + LF line extract), `test_gps_nmea` (F5.2 GGA/RMC parse + F5.3 fix validity), `test_sdlog_name` (F6.2 `FLIGHT%03u.CSV` format + next index), `test_lora_frf` (F7.2 Hz → Frf), `test_packet_v1` (F7.4 pack/unpack/CRC-16/CCITT-FALSE), `test_mission_sm` (F8.1/F8.4 state walk + BURST latch + edge profiles), `test_schedule` (F8.2 LoRa/camera periods + due; F10.3 APRS 60 s), `test_packetizer` (F8.3 fill + pack golden), `test_aprs_at` (F10.1 AT format / ACK parse), `test_aprs_ax25` (F10.2 AX.25 UI / APRS position encode; **F10.4 soft-exit host proof** of frame build without RF).

## Manual execution policy

- **Developers** run host tests on their machine after changes.
- **Cursor agents** may create and update tests and this README, but **must not execute** the test suite unless the user explicitly asks in that message.
- After adding tests, agents must tell you the exact command to run (copied from this file).

## How to run

```bash
cd balloon-project-stm32mx/tests/host
make
./test_imu_scale
./test_ms5611_crc
./test_ms5611_adc
./test_ms5611_comp
./test_max31865_cvd
./test_gps_rx
./test_gps_nmea
./test_lora_frf
./test_packet_v1
./test_sdlog_name
./test_mission_sm
./test_schedule
./test_packetizer
./test_aprs_at
./test_aprs_ax25
```

Ground decoder (F7.4 — host CLI, not in this Makefile):

```bash
cd ground
make
./decode_packet 0102002a00bc614e1683fed0f8b4073805dc05c8092effff05086ecf --rssi -72 --snr 9.5
```

Clean:

```bash
make clean
```

Requirements: host `cc` (clang/gcc) and `libm`.

## Verification log

| Test | Result | Date | Notes |
|---|---|---|---|
| `test_imu_scale` | pass | 2026-08-09 | Manual run by developer (`make` + `./test_imu_scale`) |
| `test_ms5611_crc` | pass | 2026-08-09 | Manual run (`make` + `./test_ms5611_crc`); AN520 golden vector |
| `test_ms5611_adc` | pending | — | Run `make && ./test_ms5611_adc` after F3.2 changes |
| `test_ms5611_comp` | pending | — | Run `make && ./test_ms5611_comp` after F3.3/F3.4 changes (comp + ISA + sample-from-raw) |
| `test_max31865_cvd` | pass | 2026-08-15 | Manual run (`make` + `./test_max31865_cvd`); F4.2 CVD + F4.3 `temp_sample_from_raw` composition; clean build (no warnings) |
| `test_gps_rx` | pass | 2026-08-19 | Manual run (`make` + `./test_gps_rx`); sequential two-line drain + last-line-wins; wrap uses valid trailing line |
| `test_gps_nmea` | pass | 2026-08-19 | Manual run (`make` + `./test_gps_nmea`); F5.2 GGA/RMC parse + F5.3 fix validity (52 checks) |
| `test_lora_frf` | pass | 2026-08-20 | Manual run (`make` + `./test_lora_frf`); golden Frf 915 MHz `0xE4C000`, 868 MHz `0xD90000` |
| `test_packet_v1` | pending | — | Run `make clean && make && ./test_packet_v1` after F7.4 changes; golden rich hex `0102002a00bc614e1683fed0f8b4073805dc05c8092effff05086ecf`; minimal CRC `0x18EF` (26-byte payload `0100…ffff0000`) |
| `test_sdlog_name` | pending | — | Run `make && ./test_sdlog_name` after F6.2 name/index helper changes |
| `test_mission_sm` | pass | 2026-09-05 | F8.1/F8.4: PAD→…→BEACON + BURST latch + freefall + edge gates (no-arm, no false ASCENT/FLOAT/LANDED, short freefall); re-run `make && ./test_mission_sm` after F8.4 |
| `test_schedule` | pass | 2026-09-05 | F8.2 period table + due timing + state-change / cam-off; F10.3 APRS 60 s due (`make && ./test_schedule`) |
| `test_packetizer` | pass | 2026-09-05 | F8.3 fill fields + temp override + fill→pack golden CRC (`make && ./test_packetizer`) |
| `test_aprs_at` | pending | — | Run `make && ./test_aprs_at` after F10.1 changes; locked SETGROUP/VOLUME/FILTER strings + ACK `:0` parse |
| `test_aprs_ax25` | pending | — | Run `make && ./test_aprs_ax25` after F10.2/F10.4; lat/lon/info, FCS `0x14AD`, UI frame + NRZI bitstream; **F10.4 soft-exit host gate** (no-RF frame proof) |

## What belongs here vs on the bench

| Test type | Location |
|---|---|
| Scale, endian, CRC, parse, compensation math | `tests/host/` (this tree) — **software gate** for pure logic; not a substitute for bench |
| WHO_AM_I, SPI transfers, sensor physics, RF | Roadmap **§21 Bench verification backlog** |
| Full stack soak, fail-soft under stress | Roadmap **§16 Phase F11 (HIL)** |

See [Firmware Development Guidelines.md](../../Software%20Documents/Firmware%20Development%20Guidelines.md) for the full verification workflow.

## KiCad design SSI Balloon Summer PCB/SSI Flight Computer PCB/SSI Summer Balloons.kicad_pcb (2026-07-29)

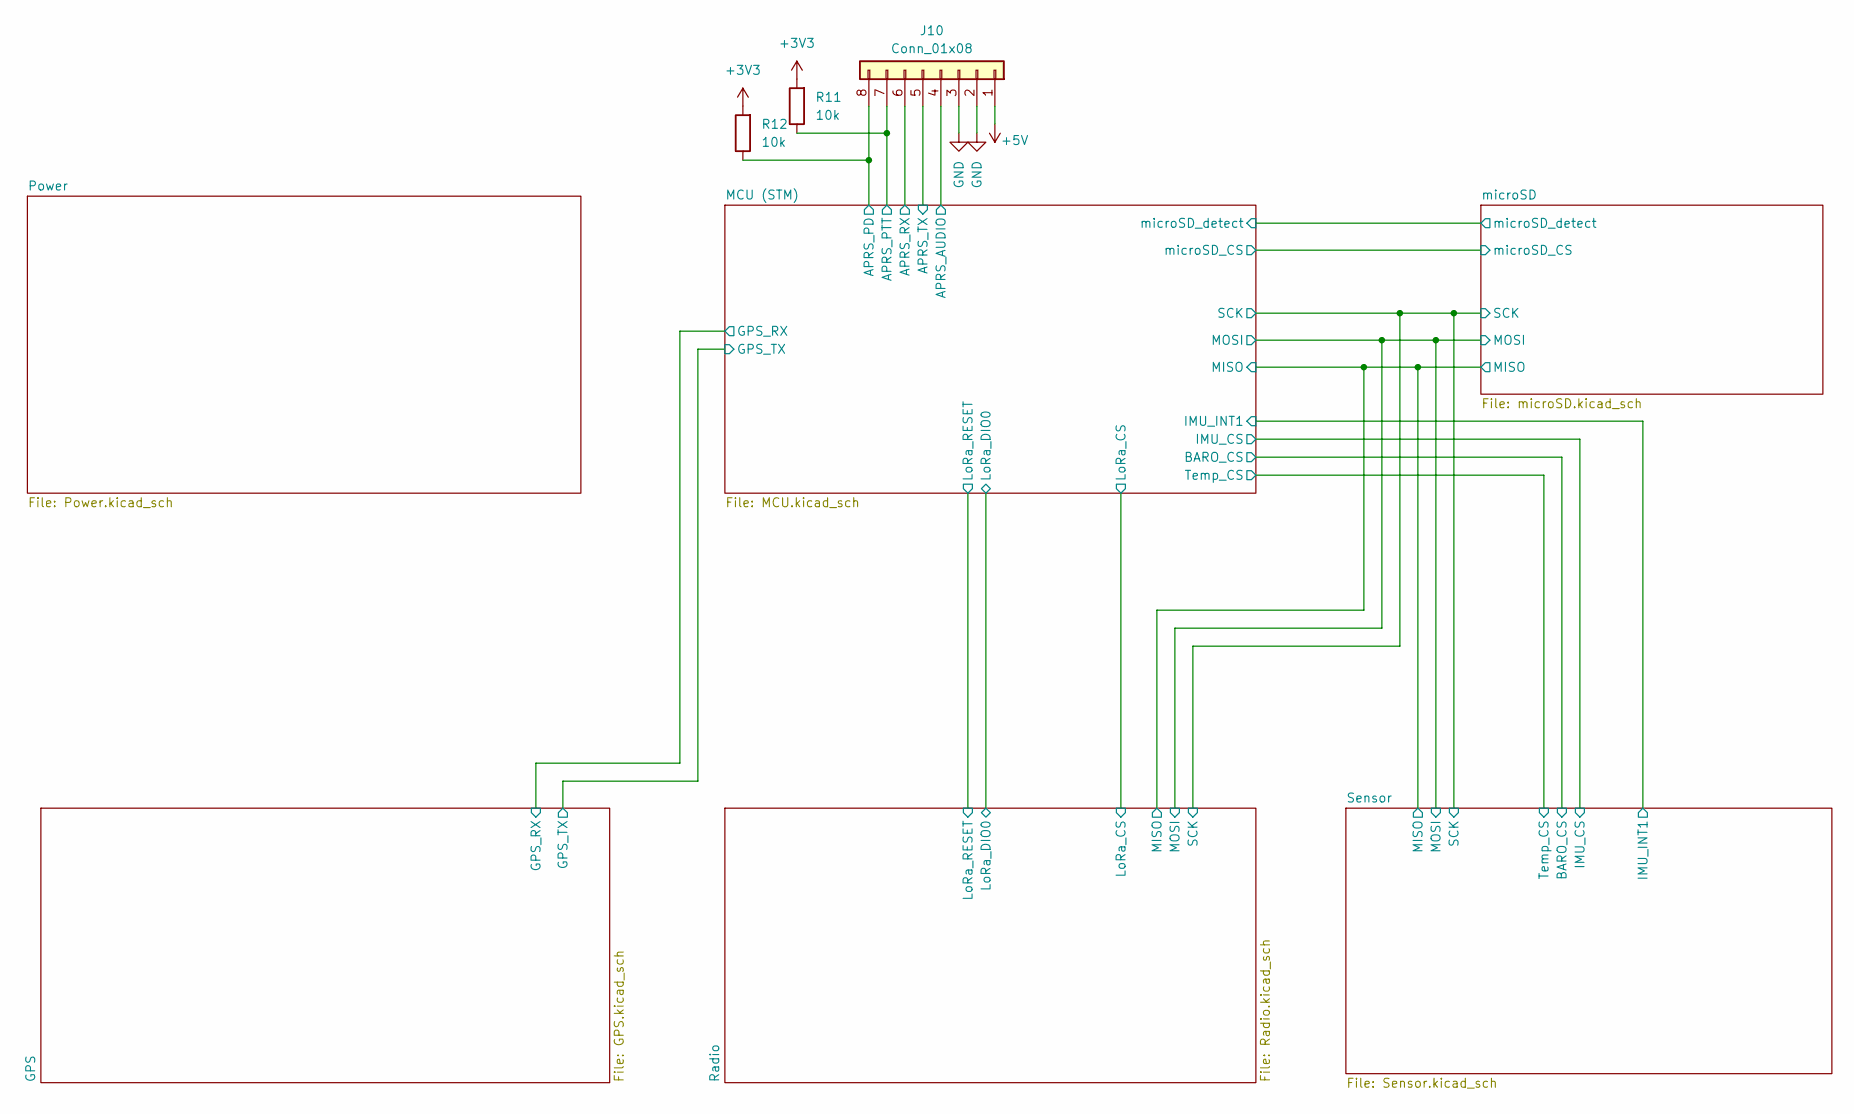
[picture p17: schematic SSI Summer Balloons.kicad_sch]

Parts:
J10: Conn_01x08; JST_XH_S8B-XH-A-1_1x08_P2.50mm_Horizontal; LCSC C157914
R11, R12: 10k; R_0603_1608Metric; LCSC C25804

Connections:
+3V3: R11.2, R12.2; also elsewhere on the board
+5V: J10.1; also elsewhere on the board
/MCU (STM)/APRS_AUDIO: J10.4; also elsewhere on the board
/MCU (STM)/APRS_PD: J10.8, R12.1; also elsewhere on the board
/MCU (STM)/APRS_PTT: J10.7, R11.1; also elsewhere on the board
/MCU (STM)/APRS_RX: J10.6; also elsewhere on the board
/MCU (STM)/APRS_TX: J10.5; also elsewhere on the board
GND: J10.2, J10.3; also elsewhere on the board

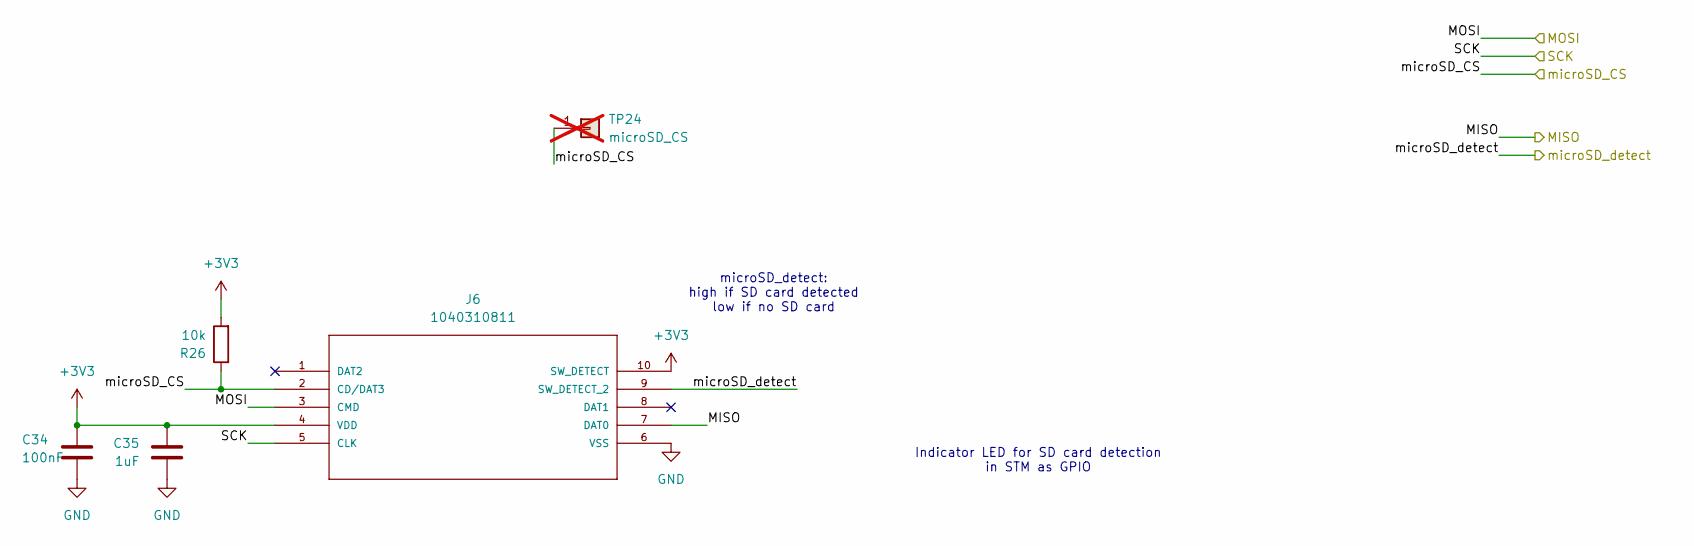
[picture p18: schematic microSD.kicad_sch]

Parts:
C34: 100nF; C_0603_1608Metric; LCSC C14663
C35: 1uF; C_0603_1608Metric; LCSC C29936
J6: 1040310811; 104031-0811_MOL; MANUFACTURER_PART_NUMBER 1040310811; LCSC C585350
R26: 10k; R_0603_1608Metric; LCSC C25804
TP24: microSD_CS; PinHeader_1x01_P2.54mm_Vertical; LCSC C81276; not fitted

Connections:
+3V3: C34.1, C35.1, J6.4 (VDD), J6.10 (SW_DETECT), R26.2; also elsewhere on the board
/MCU (STM)/MISO: J6.7 (DAT0); also elsewhere on the board
/MCU (STM)/MOSI: J6.3 (CMD); also elsewhere on the board
/MCU (STM)/SCK: J6.5 (CLK); also elsewhere on the board
/MCU (STM)/microSD_CS: J6.2 (CD/DAT3), R26.1, TP24.1 (Pin_1_1); also elsewhere on the board
/MCU (STM)/microSD_detect: J6.9 (SW_DETECT_2); also elsewhere on the board
GND: C34.2, C35.2, J6.6 (VSS); also elsewhere on the board

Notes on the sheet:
microSD_detect: high if SD card detected low if no SD card
Indicator LED for SD card detection in STM as GPIO

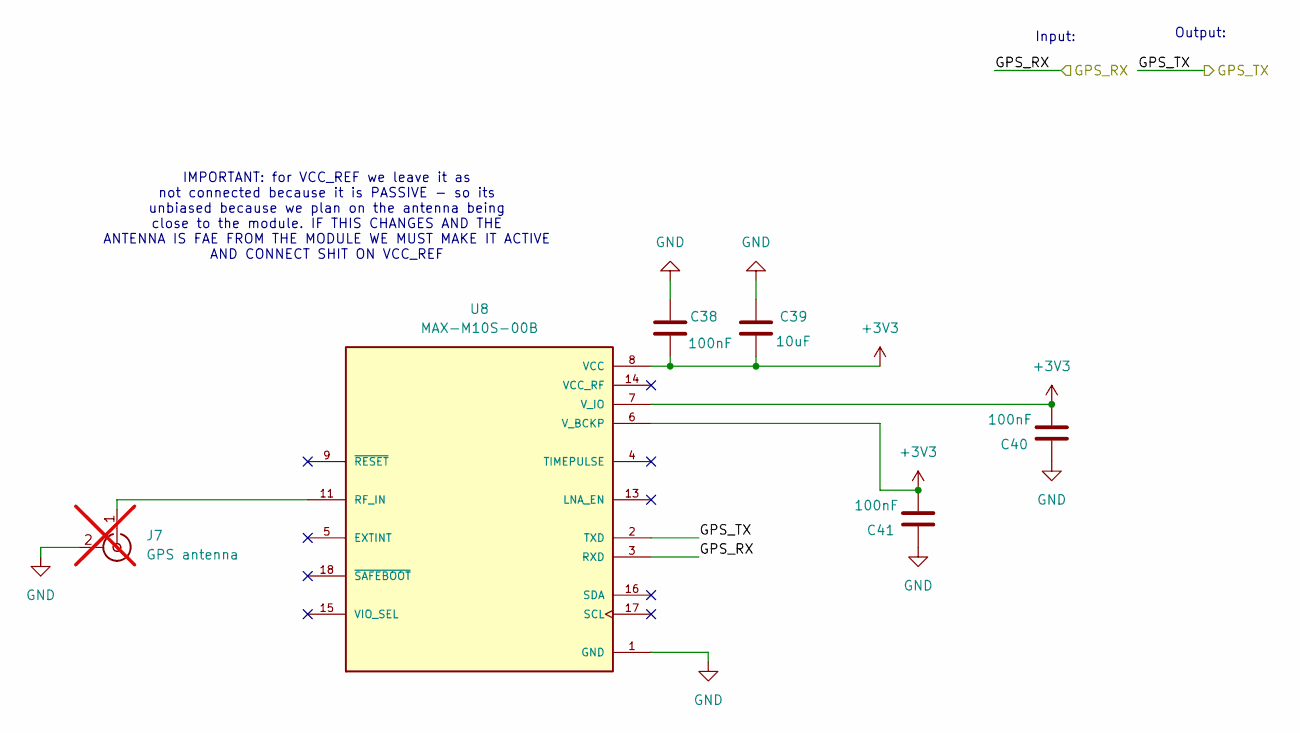
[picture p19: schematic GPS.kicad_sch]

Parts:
C38, C40, C41: 100nF; C_0603_1608Metric; LCSC C14663
C39: 10uF; C_0805_2012Metric; LCSC C15850
J7: GPS antenna; SMA_Amphenol_901-144_Vertical; LCSC C376663; not fitted
U8: MAX-M10S-00B; XCVR_MAX-M10S-00B; PARTREV C1; LCSC C4153167

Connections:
+3V3: C38.2, C39.2, C40.2, C41.2, U8.6 (V_BCKP), U8.7 (V_IO), U8.8 (VCC); also elsewhere on the board
GND: C38.1, C39.1, C40.1, C41.1, J7.2 (Ext), U8.1 (GND), U8.10 (GND), U8.12 (GND); also elsewhere on the board
unnamed 40: J7.1 (In), U8.11 (RF_IN); also elsewhere on the board

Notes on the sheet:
IMPORTANT: for VCC_REF we leave it as not connected because it is PASSIVE - so its unbiased because we plan on the antenna being close to the module. IF THIS CHANGES AND THE ANTENNA IS FAE FROM THE MODULE WE MUST MAKE IT ACTIVE AND CONNECT SHIT ON VCC_REF
Output:
Input:

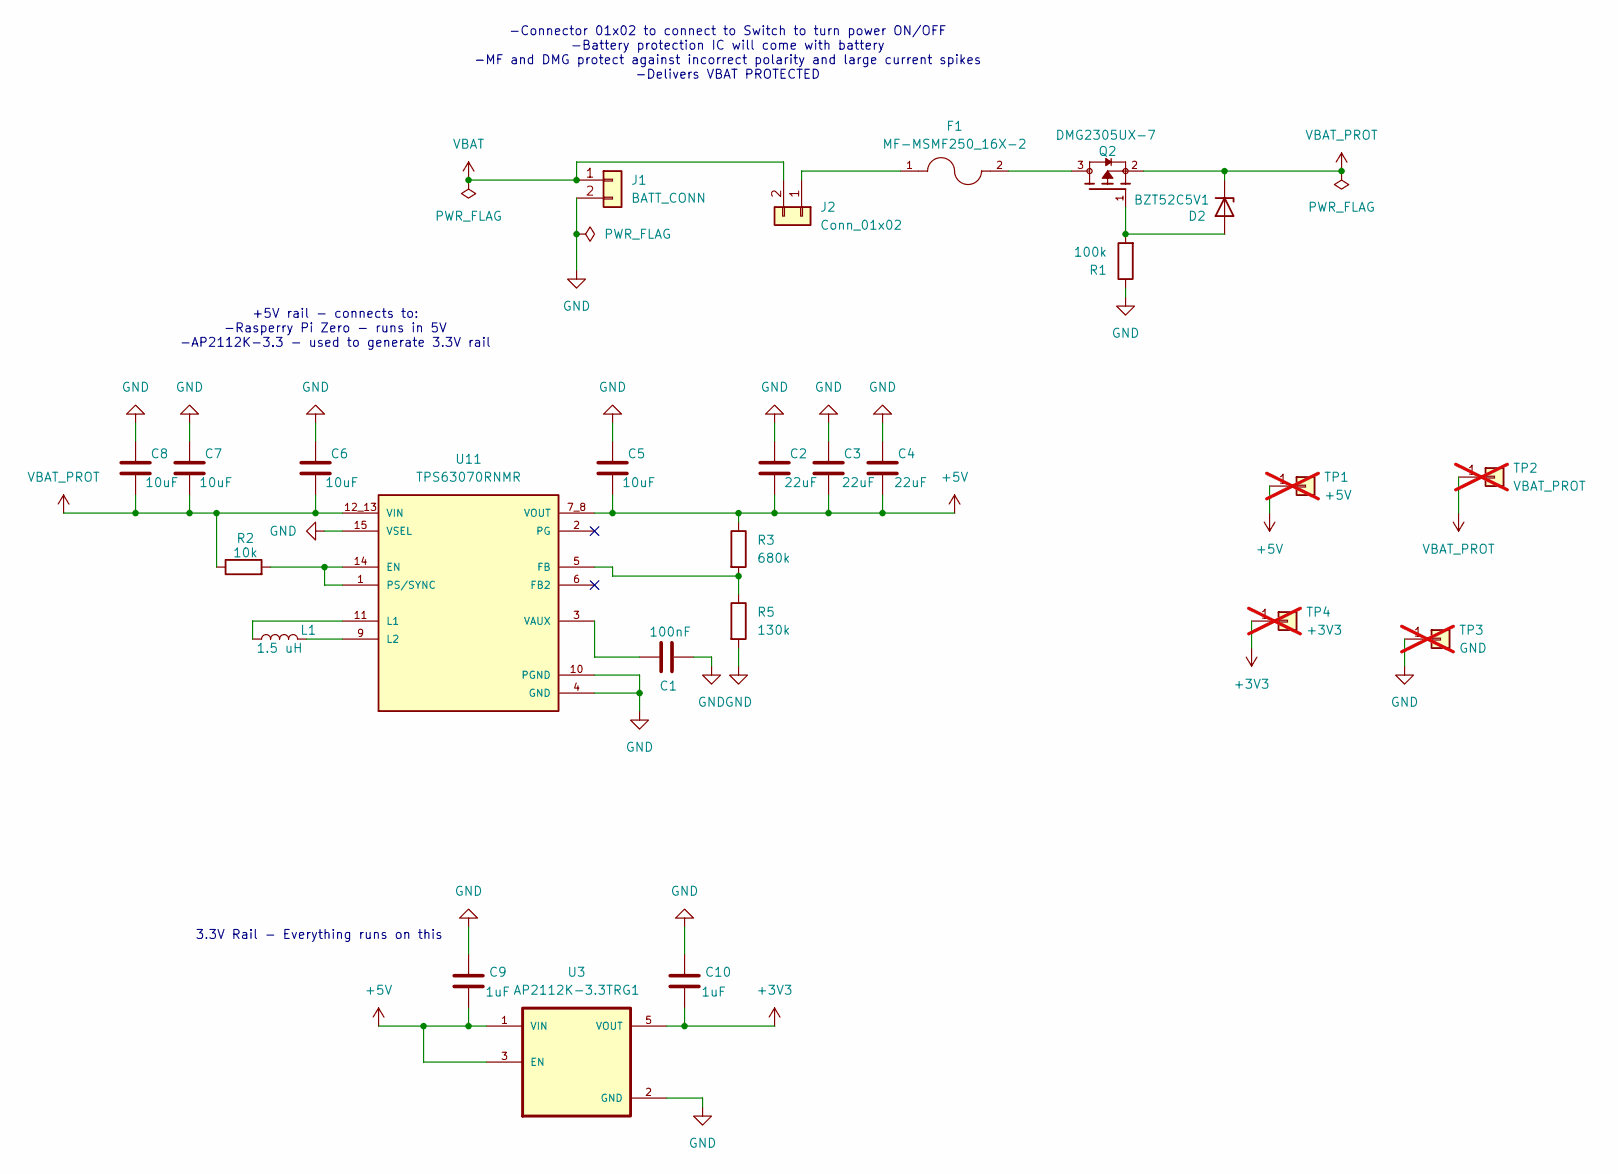
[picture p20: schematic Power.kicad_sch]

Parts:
C1: 100nF; C_0603_1608Metric; LCSC C14663
C2, C3, C4: 22uF; C_0805_2012Metric; LCSC C45783
C5, C6: 10uF; C_0603_1608Metric; LCSC C96446
C7, C8: 10uF; C_0805_2012Metric; LCSC C15850
C9, C10: 1uF; C_0603_1608Metric; LCSC C29936
D2: BZT52C5V1; D_SOD-123; LCSC C2117
F1: MF-MSMF250_16X-2; FUSER_MF-MSMF250_16X-2; LCSC C210838
J1: BATT_CONN; JST_XH_B2B-XH-A_1x02_P2.50mm_Vertical; LCSC C265283
J2: Conn_01x02; JST_XH_B2B-XH-A_1x02_P2.50mm_Vertical; LCSC C265283
L1: 1.5 uH; L_Coilcraft_XxL4020; LCSC C18547833
Q2: DMG2305UX-7; SOT91P240X110-3N_DMG2305UX-7; PARTREV 09/2018; LCSC C5261054
R1: 100k; R_0603_1608Metric; LCSC C25803
R2: 10k; R_0603_1608Metric; LCSC C25804
R3: 680k; R_0603_1608Metric; LCSC C25822
R5: 130k; R_0603_1608Metric; LCSC C22795
TP1: +5V; PinHeader_1x01_P2.54mm_Vertical; LCSC C81276; not fitted
TP2: VBAT_PROT; PinHeader_1x01_P2.54mm_Vertical; LCSC C81276; not fitted
TP3: GND; PinHeader_1x01_P2.54mm_Vertical; LCSC C81276; not fitted
TP4: +3V3; PinHeader_1x01_P2.54mm_Vertical; LCSC C81276; not fitted
U3: AP2112K-3.3TRG1; SOT95P285X140-5N; PARTREV 2-2; LCSC C51118
U11: TPS63070RNMR; VREG_TPS63070RNMR; PARTREV B; LCSC C109322

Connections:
+3V3: C10.2, TP4.1 (Pin_1_1), U3.5 (VOUT); also elsewhere on the board
+5V: C2.2, C3.2, C4.2, C5.2, C9.2, R3.1, TP1.1 (Pin_1_1), U3.1 (VIN), U3.3 (EN), U11.7_8 (VOUT); also elsewhere on the board
GND: C1.2, C2.1, C3.1, C4.1, C5.1, C6.1, C7.1, C8.1, C9.1, C10.1, J1.2, R1.1, R5.2, TP3.1 (Pin_1_1), U3.2 (GND), U11.4 (GND), U11.10 (PGND), U11.15 (VSEL); also elsewhere on the board
unnamed: D2.2 (A), Q2.1, R1.2
unnamed: F1.2, Q2.3
unnamed: F1.1, J2.1
unnamed: R2.2, U11.1 (PS/SYNC), U11.14 (EN)
unnamed: R3.2, R5.1, U11.5 (FB)
unnamed: L1.1, U11.11 (L1)
unnamed: L1.2, U11.9 (L2)
unnamed: C1.1, U11.3 (VAUX)
VBAT: J1.1, J2.2
VBAT_PROT: C6.2, C7.2, C8.2, D2.1 (K), Q2.2, R2.1, TP2.1 (Pin_1_1), U11.12_13 (VIN)

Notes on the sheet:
-Connector 01x02 to connect to Switch to turn power ON/OFF -Battery protection IC will come with battery -MF and DMG protect against incorrect polarity and large current spikes -Delivers VBAT PROTECTED
3.3V Rail - Everything runs on this
+5V rail - connects to: -Rasperry Pi Zero - runs in 5V -AP2112K-3.3 - used to generate 3.3V rail

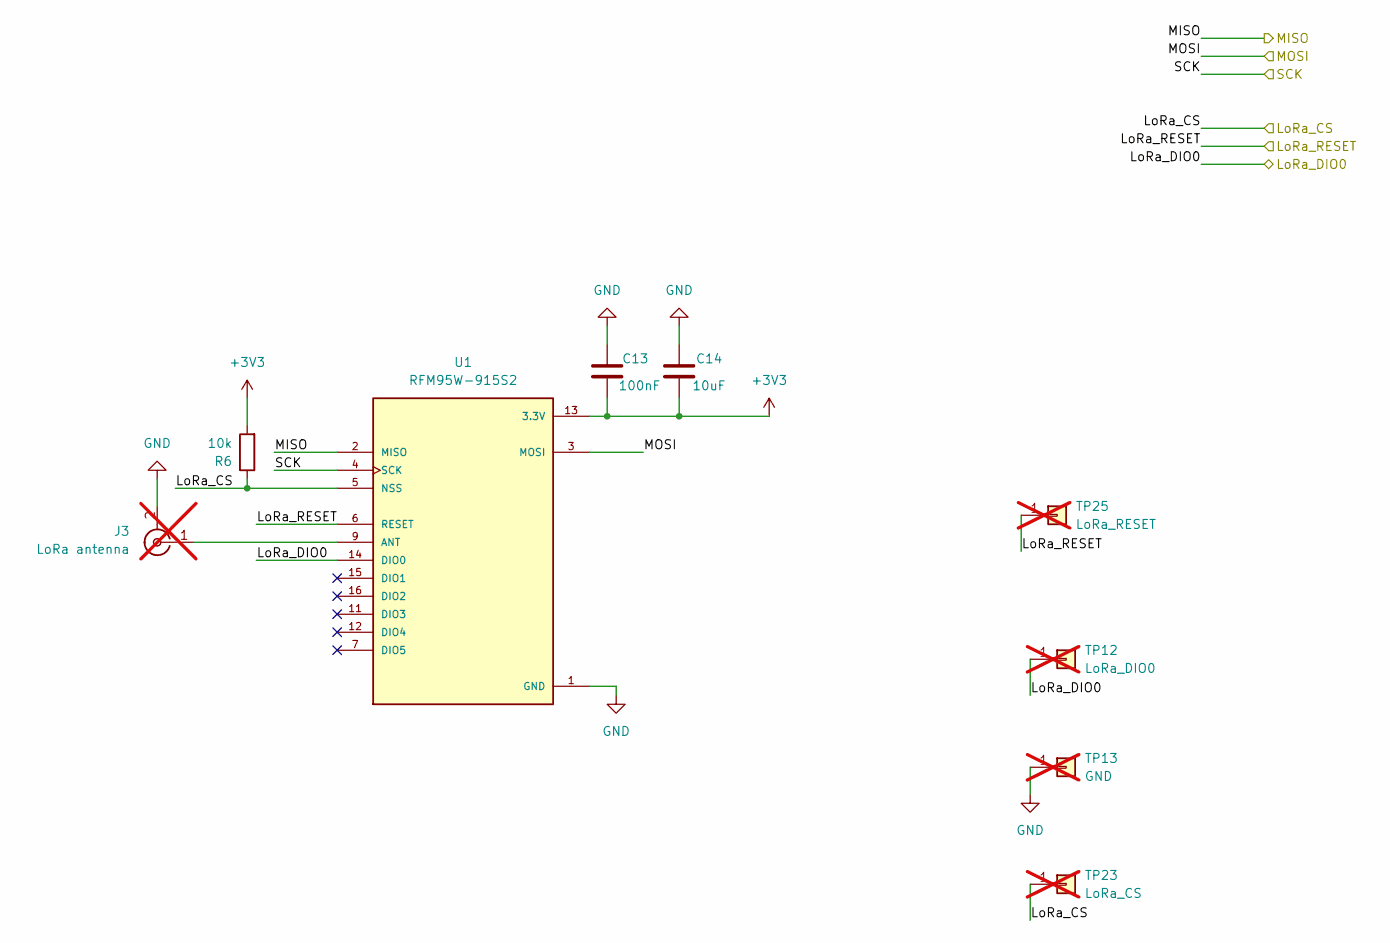
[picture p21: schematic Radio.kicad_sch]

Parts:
C13: 100nF; C_0603_1608Metric; LCSC C14663
C14: 10uF; C_0805_2012Metric; LCSC C15850
J3: LoRa antenna; SMA_Amphenol_901-144_Vertical; LCSC C376663; not fitted
R6: 10k; R_0603_1608Metric; LCSC C25804
TP12: LoRa_DIO0; PinHeader_1x01_P2.54mm_Vertical; LCSC C81276; not fitted
TP13: GND; PinHeader_1x01_P2.54mm_Vertical; LCSC C81276; not fitted
TP23: LoRa_CS; PinHeader_1x01_P2.54mm_Vertical; LCSC C81276; not fitted
TP25: LoRa_RESET; PinHeader_1x01_P2.54mm_Vertical; LCSC C81276; not fitted
U1: RFM95W-915S2; XCVR_RFM95W-915S2; LCSC C2844473

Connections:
+3V3: C13.2, C14.2, R6.2, U1.13 (3.3V); also elsewhere on the board
/MCU (STM)/LoRa_CS: R6.1, TP23.1 (Pin_1_1), U1.5 (NSS); also elsewhere on the board
/MCU (STM)/LoRa_DIO0: TP12.1 (Pin_1_1), U1.14 (DIO0); also elsewhere on the board
/MCU (STM)/LoRa_RESET: TP25.1 (Pin_1_1), U1.6 (RESET); also elsewhere on the board
GND: C13.1, C14.1, J3.2 (Ext), TP13.1 (Pin_1_1), U1.1 (GND), U1.8 (GND), U1.10 (GND); also elsewhere on the board
unnamed 39: J3.1 (In), U1.9 (ANT); also elsewhere on the board

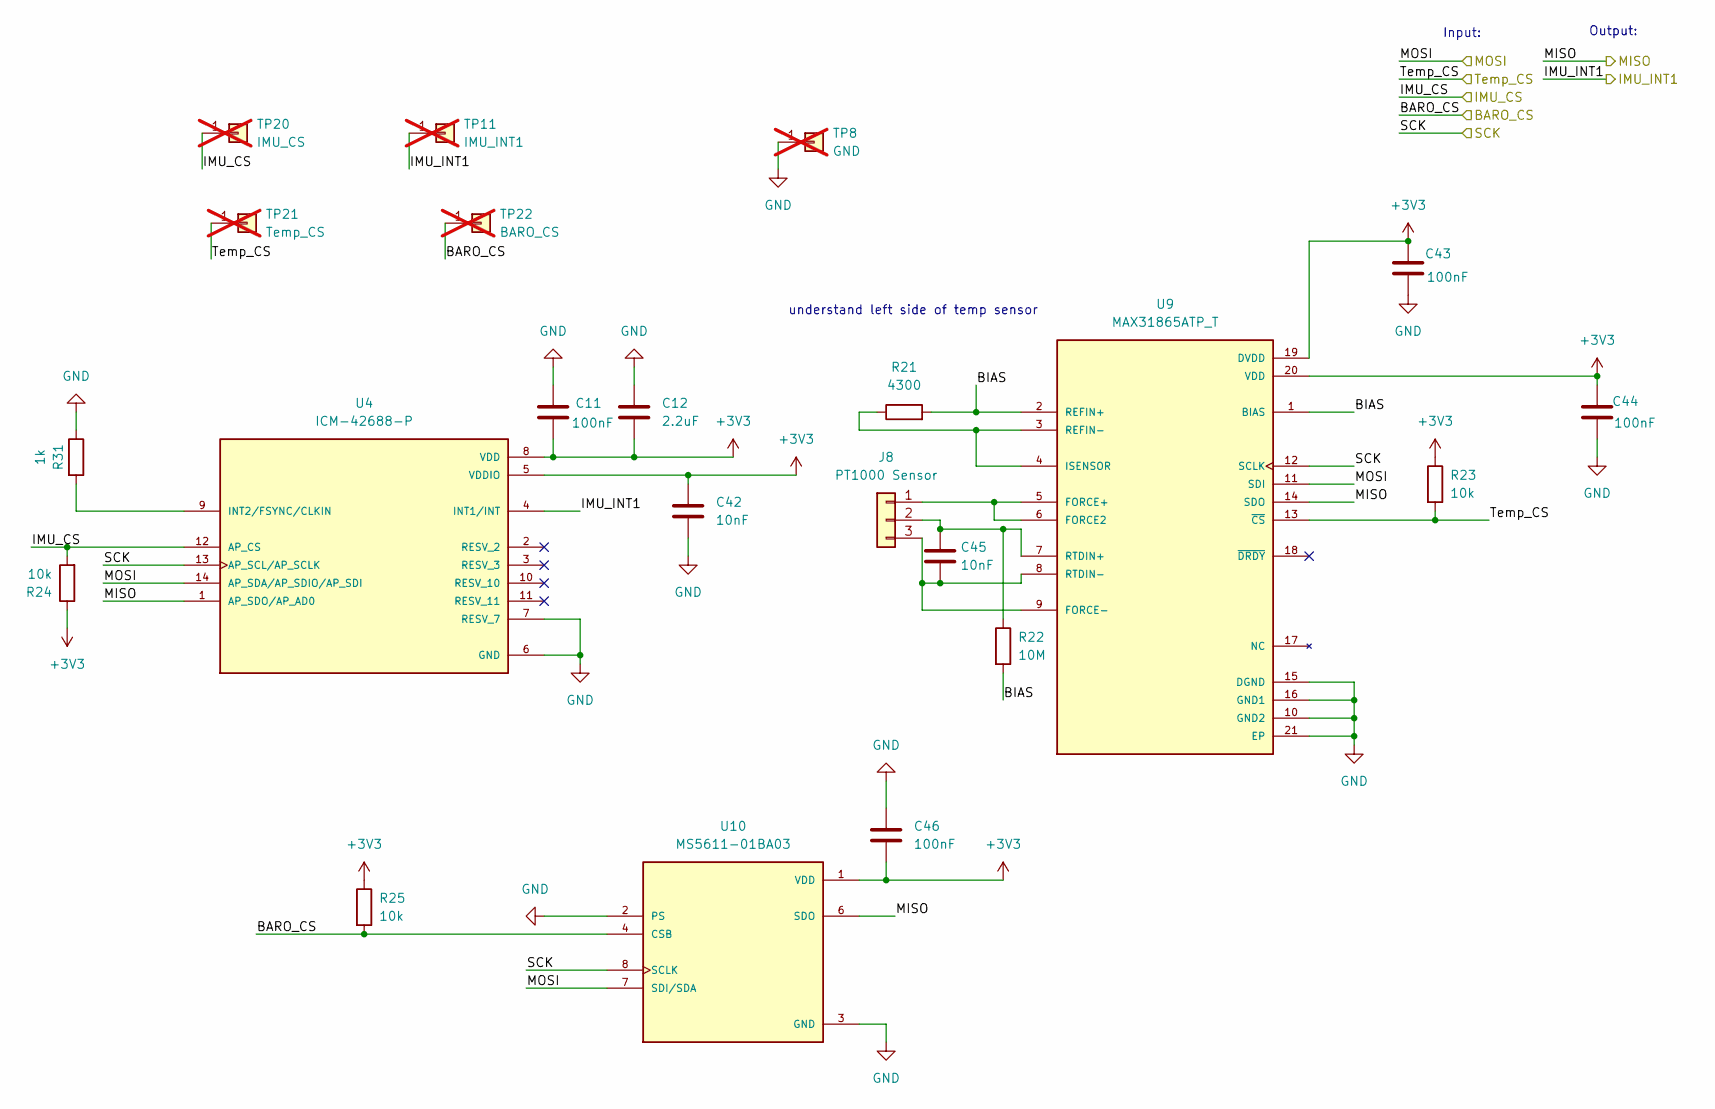
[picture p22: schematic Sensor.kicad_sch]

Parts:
C11, C43, C44, C46: 100nF; C_0603_1608Metric; LCSC C14663
C12: 2.2uF; C_0603_1608Metric; LCSC C43922
C42, C45: 10nF; C_0603_1608Metric; LCSC C57112
J8: PT1000 Sensor; JST_PH_B3B-PH-K_1x03_P2.00mm_Vertical; LCSC C158004
R21: 4300; R_0603_1608Metric; LCSC C2989227
R22: 10M; R_0603_1608Metric; LCSC C7250
R23, R24, R25: 10k; R_0603_1608Metric; LCSC C25804
R31: 1k; R_0603_1608Metric; LCSC C21190
TP8: GND; PinHeader_1x01_P2.54mm_Vertical; LCSC C81276; not fitted
TP11: IMU_INT1; PinHeader_1x01_P2.54mm_Vertical; LCSC C81276; not fitted
TP20: IMU_CS; PinHeader_1x01_P2.54mm_Vertical; LCSC C81276; not fitted
TP21: Temp_CS; PinHeader_1x01_P2.54mm_Vertical; LCSC C81276; not fitted
TP22: BARO_CS; PinHeader_1x01_P2.54mm_Vertical; LCSC C81276; not fitted
U4: ICM-42688-P; PQFN50P300X250X97-14N; PARTREV 1.2; LCSC C1850418
U9: MAX31865ATP_T; QFN65P500X500X80-21N; PARTREV 3; LCSC C118474
U10: MS5611-01BA03; SON125P500X300X100-8N; PARTREV 06/2017; LCSC C15639

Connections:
+3V3: C11.2, C12.2, C42.1, C43.1, C44.1, C46.2, R23.1, R24.1, R25.1, U4.5 (VDDIO), U4.8 (VDD), U9.19 (DVDD), U9.20 (VDD), U10.1 (VDD); also elsewhere on the board
/MCU (STM)/BARO_CS: R25.2, TP22.1 (Pin_1_1), U10.4 (CSB), U10.5 (CSB); also elsewhere on the board
/MCU (STM)/IMU_CS: R24.2, TP20.1 (Pin_1_1), U4.12 (AP_CS); also elsewhere on the board
/MCU (STM)/IMU_INT1: TP11.1 (Pin_1_1), U4.4 (INT1/INT); also elsewhere on the board
/MCU (STM)/MISO: U4.1 (AP_SDO/AP_AD0), U9.14 (SDO), U10.6 (SDO); also elsewhere on the board
/MCU (STM)/MOSI: U4.14 (AP_SDA/AP_SDIO/AP_SDI), U9.11 (SDI), U10.7 (SDI/SDA); also elsewhere on the board
/MCU (STM)/SCK: U4.13 (AP_SCL/AP_SCLK), U9.12 (SCLK), U10.8 (SCLK); also elsewhere on the board
/MCU (STM)/Temp_CS: R23.2, TP21.1 (Pin_1_1), U9.13 (~CS); also elsewhere on the board
/Sensor/BIAS: R21.2, R22.2, U9.1 (BIAS), U9.2 (REFIN+)
GND: C11.1, C12.1, C42.2, C43.2, C44.2, C46.1, R31.1, TP8.1 (Pin_1_1), U4.6 (GND), U4.7 (RESV_7), U9.10 (GND2), U9.15 (DGND), U9.16 (GND1), U9.21 (EP), U10.2 (PS), U10.3 (GND); also elsewhere on the board
unnamed: J8.1, U9.5 (FORCE+), U9.6 (FORCE2)
unnamed: C45.1, J8.2, R22.1, U9.7 (RTDIN+)
unnamed: C45.2, J8.3, U9.8 (RTDIN-), U9.9 (FORCE-)
unnamed: R31.2, U4.9 (INT2/FSYNC/CLKIN)
unnamed: R21.1, U9.3 (REFIN-), U9.4 (ISENSOR)

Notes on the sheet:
Output:
understand left side of temp sensor
Input:

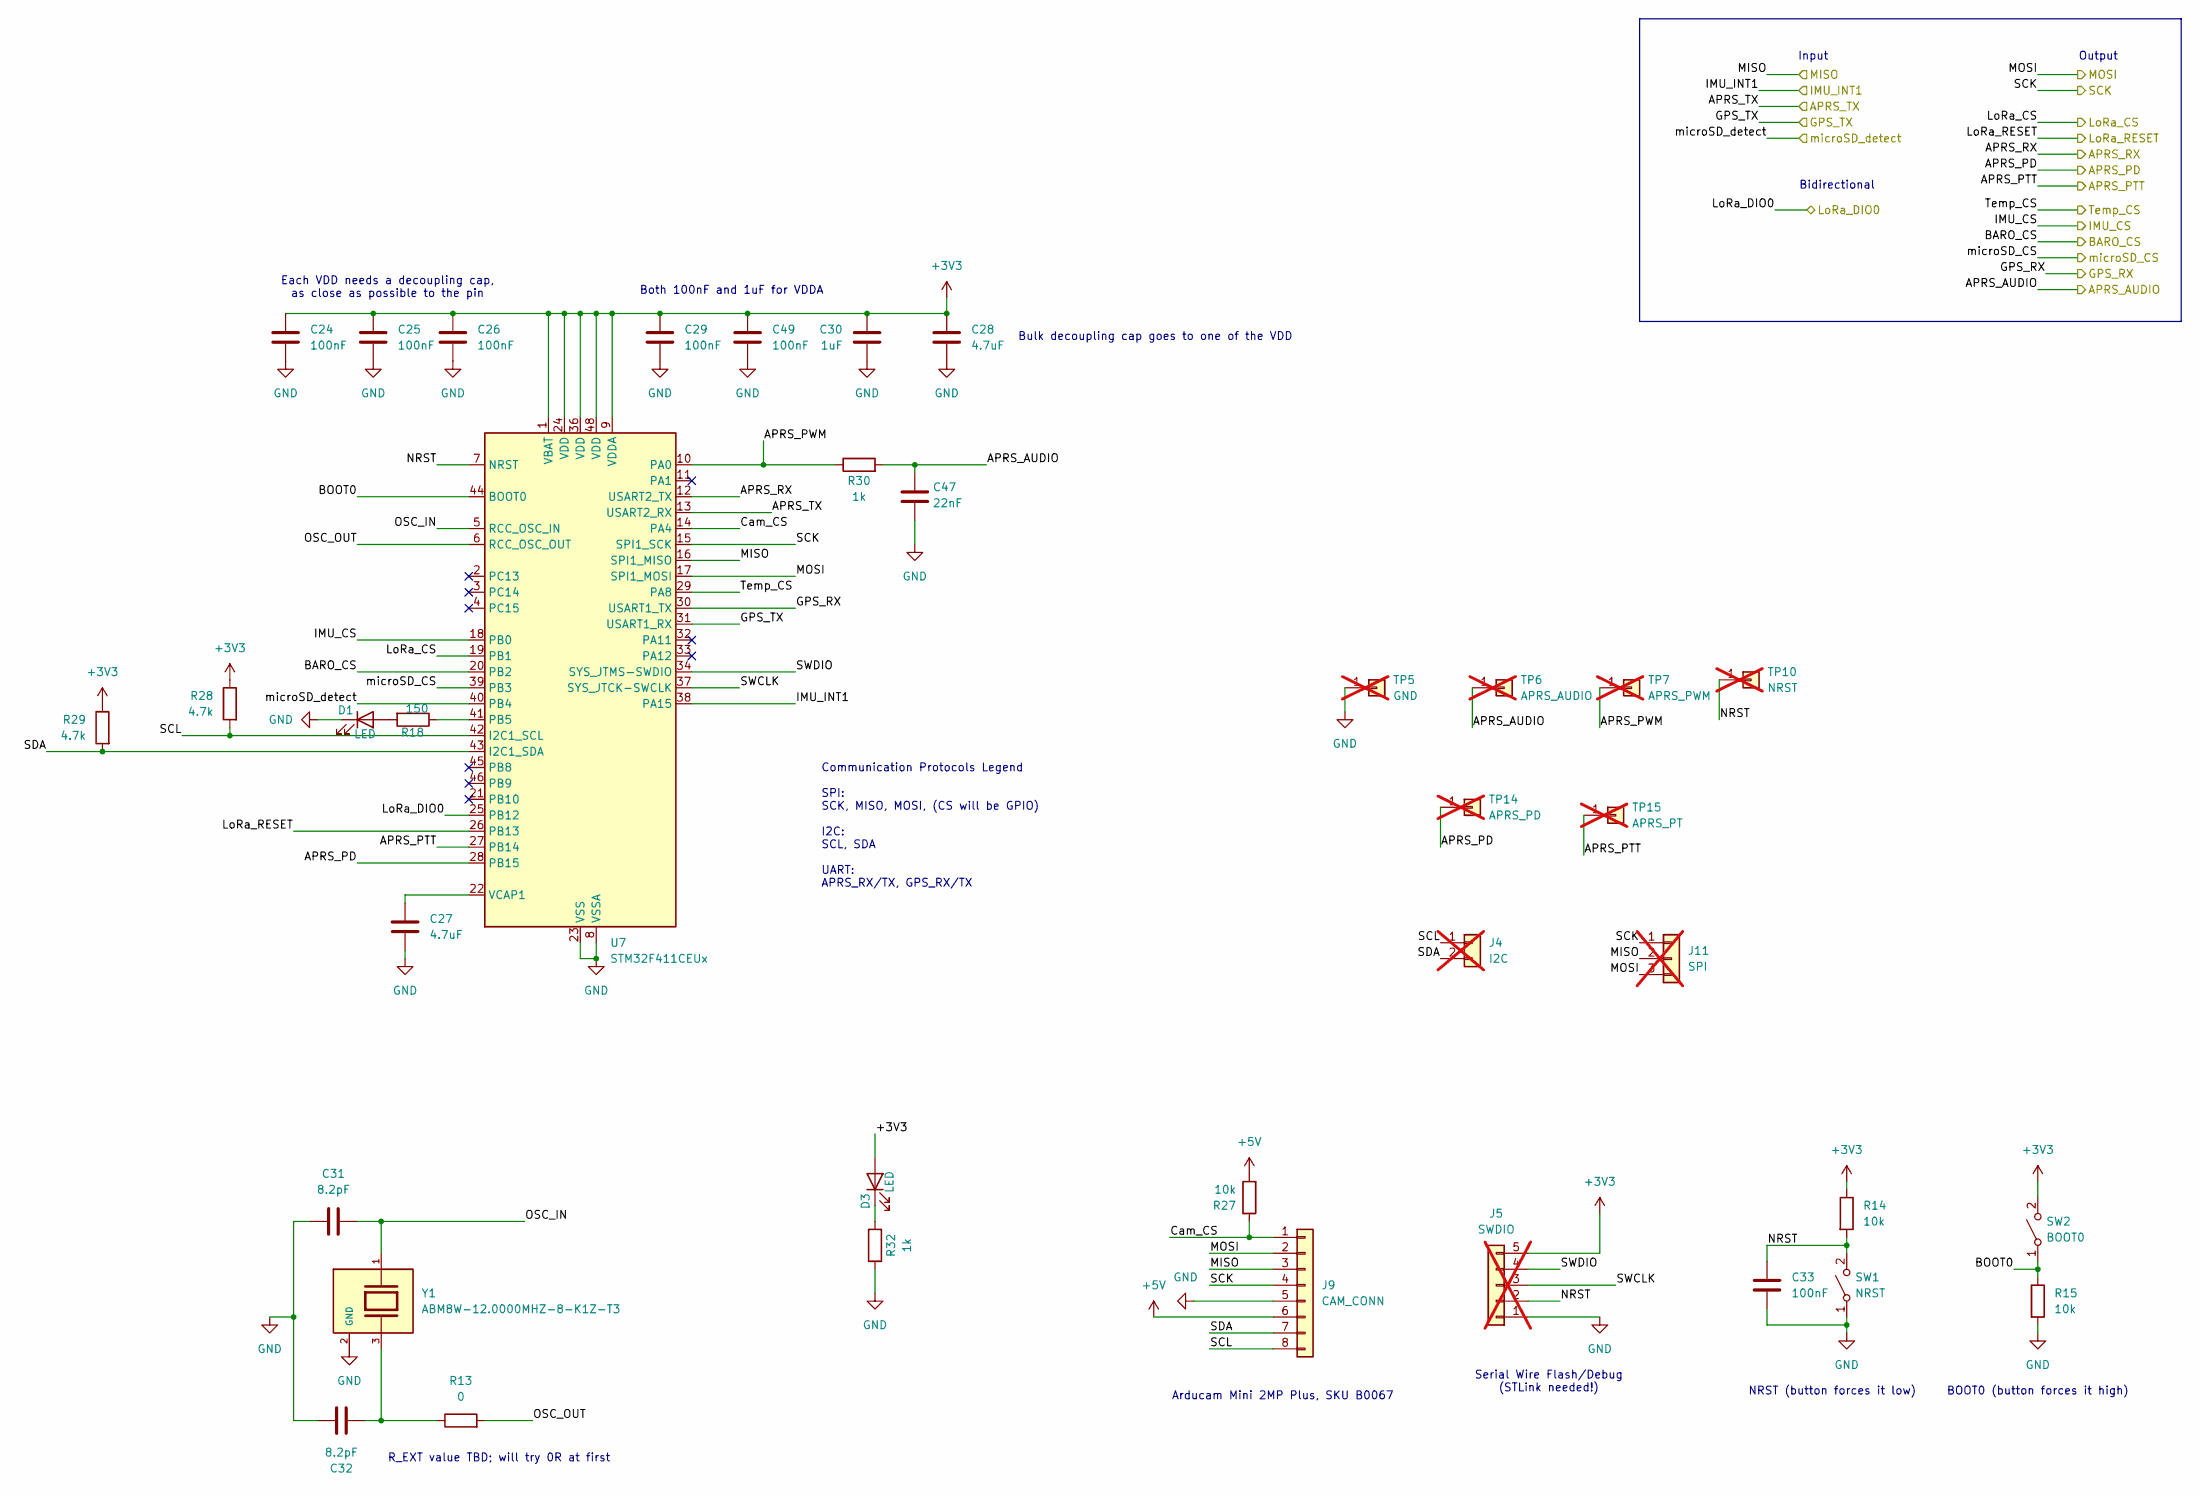
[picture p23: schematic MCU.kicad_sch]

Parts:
C24, C25, C26, C29, C33, C49: 100nF; C_0603_1608Metric; LCSC C14663
C27, C28: 4.7uF; C_0805_2012Metric; LCSC C76639
C30: 1uF; C_0603_1608Metric; LCSC C29936
C31, C32: 8.2pF; C_0603_1608Metric; LCSC C1685
C47: 22nF; C_0603_1608Metric; LCSC C49326627
D1: LED; LED_0805_2012Metric; LCSC C2297
D3: LED; LED_0805_2012Metric; LCSC C84256
J4: I2C; PinHeader_1x02_P2.54mm_Vertical; LCSC C168673; not fitted
J5: SWDIO; PinHeader_1x05_P2.54mm_Vertical; LCSC C5156614; not fitted
J9: CAM_CONN; JST_XH_B8B-XH-A_1x08_P2.50mm_Vertical; LCSC C161875
J11: SPI; PinHeader_1x03_P2.54mm_Vertical; LCSC C49257; not fitted
R13: 0; R_0603_1608Metric; LCSC C21189
R14, R15, R27: 10k; R_0603_1608Metric; LCSC C25804
R18: 150; R_0603_1608Metric; LCSC C22808
R28, R29: 4.7k; R_0603_1608Metric; LCSC C98195
R30, R32: 1k; R_0603_1608Metric; LCSC C21190
SW1: NRST; SW_SPST_B3U-1000P; LCSC C720477
SW2: BOOT0; SW_SPST_B3U-1000P; LCSC C720477
TP5: GND; PinHeader_1x01_P2.54mm_Vertical; LCSC C81276; not fitted
TP6: APRS_AUDIO; PinHeader_1x01_P2.54mm_Vertical; LCSC C81276; not fitted
TP7: APRS_PWM; PinHeader_1x01_P2.54mm_Vertical; LCSC C81276; not fitted
TP10: NRST; PinHeader_1x01_P2.54mm_Vertical; LCSC C81276; not fitted
TP14: APRS_PD; PinHeader_1x01_P2.54mm_Vertical; LCSC C81276; not fitted
TP15: APRS_PT; PinHeader_1x01_P2.54mm_Vertical; LCSC C81276; not fitted
U7: STM32F411CEUx; QFN-48-1EP_7x7mm_P0.5mm_EP5.6x5.6mm; LCSC C60420
Y1: ABM8W-12.0000MHZ-8-K1Z-T3; XTAL_ABM8W-12.0000MHZ-8-K1Z-T3; PARTREV 08.09.2018; DigiKey_Part_Number 535-14010-1-ND

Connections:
+3V3: C24.1, C25.1, C26.1, C28.1, C29.1, C30.1, C49.1, D3.2 (A), J5.5, R14.1, R28.1, R29.1, SW2.2 (B), U7.1 (VBAT), U7.9 (VDDA), U7.24 (VDD), U7.36 (VDD), U7.48 (VDD); also elsewhere on the board
+5V: J9.6, R27.2; also elsewhere on the board
/GPS/GPS_RX: U7.30 (USART1_TX); also elsewhere on the board
/GPS/GPS_TX: U7.31 (USART1_RX); also elsewhere on the board
/MCU (STM)/APRS_AUDIO: C47.1, R30.2, TP6.1 (Pin_1_1); also elsewhere on the board
/MCU (STM)/APRS_PD: TP14.1 (Pin_1_1), U7.28 (PB15); also elsewhere on the board
/MCU (STM)/APRS_PTT: TP15.1 (Pin_1_1), U7.27 (PB14); also elsewhere on the board
/MCU (STM)/APRS_PWM: R30.1, TP7.1 (Pin_1_1), U7.10 (PA0)
/MCU (STM)/APRS_RX: U7.12 (USART2_TX); also elsewhere on the board
/MCU (STM)/APRS_TX: U7.13 (USART2_RX); also elsewhere on the board
/MCU (STM)/BARO_CS: U7.20 (PB2); also elsewhere on the board
/MCU (STM)/BOOT0: R15.1, SW2.1 (A), U7.44 (BOOT0); also elsewhere on the board
/MCU (STM)/Cam_CS: J9.1, R27.1, U7.14 (PA4)
/MCU (STM)/IMU_CS: U7.18 (PB0); also elsewhere on the board
/MCU (STM)/IMU_INT1: U7.38 (PA15); also elsewhere on the board
/MCU (STM)/LoRa_CS: U7.19 (PB1); also elsewhere on the board
/MCU (STM)/LoRa_DIO0: U7.25 (PB12); also elsewhere on the board
/MCU (STM)/LoRa_RESET: U7.26 (PB13); also elsewhere on the board
/MCU (STM)/MISO: J9.3, J11.2, U7.16 (SPI1_MISO); also elsewhere on the board
/MCU (STM)/MOSI: J9.2, J11.3, U7.17 (SPI1_MOSI); also elsewhere on the board
/MCU (STM)/NRST: C33.1, J5.2, R14.2, SW1.2 (B), TP10.1 (Pin_1_1), U7.7 (NRST); also elsewhere on the board
/MCU (STM)/OSC_IN: C31.2, U7.5 (RCC_OSC_IN), Y1.1
/MCU (STM)/OSC_OUT: R13.2, U7.6 (RCC_OSC_OUT)
/MCU (STM)/SCK: J9.4, J11.1, U7.15 (SPI1_SCK); also elsewhere on the board
/MCU (STM)/SCL: J4.1, J9.8, R28.2, U7.42 (I2C1_SCL)
/MCU (STM)/SDA: J4.2, J9.7, R29.2, U7.43 (I2C1_SDA)
/MCU (STM)/SWCLK: J5.3, U7.37 (SYS_JTCK-SWCLK)
/MCU (STM)/SWDIO: J5.4, U7.34 (SYS_JTMS-SWDIO)
/MCU (STM)/Temp_CS: U7.29 (PA8); also elsewhere on the board
/MCU (STM)/microSD_CS: U7.39 (PB3); also elsewhere on the board
/MCU (STM)/microSD_detect: U7.40 (PB4); also elsewhere on the board
GND: C24.2, C25.2, C26.2, C27.2, C28.2, C29.2, C30.2, C31.1, C32.1, C33.2, C47.2, C49.2, D1.1 (K), J5.1, J9.5, R15.2, R32.1, SW1.1 (A), TP5.1 (Pin_1_1), U7.8 (VSSA), U7.23 (VSS), U7.35 (VSS), U7.47 (VSS), U7.49 (VSS), Y1.2 (GND), Y1.4 (GND); also elsewhere on the board
unnamed: C32.2, R13.1, Y1.3
unnamed: D1.2 (A), R18.2
unnamed: D3.1 (K), R32.2
unnamed: R18.1, U7.41 (PB5)
unnamed: C27.1, U7.22 (VCAP1)

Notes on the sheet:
Bidirectional
NRST (button forces it low)
BOOT0 (button forces it high)
Output
Input
Communication Protocols Legend SPI: SCK, MISO, MOSI, (CS will be GPIO) I2C: SCL, SDA UART: APRS_RX/TX, GPS_RX/TX
R_EXT value TBD; will try 0R at first
Both 100nF and 1uF for VDDA
Each VDD needs a decoupling cap, as close as possible to the pin
Arducam Mini 2MP Plus, SKU B0067
Serial Wire Flash/Debug (STLink needed!)
Bulk decoupling cap goes to one of the VDD

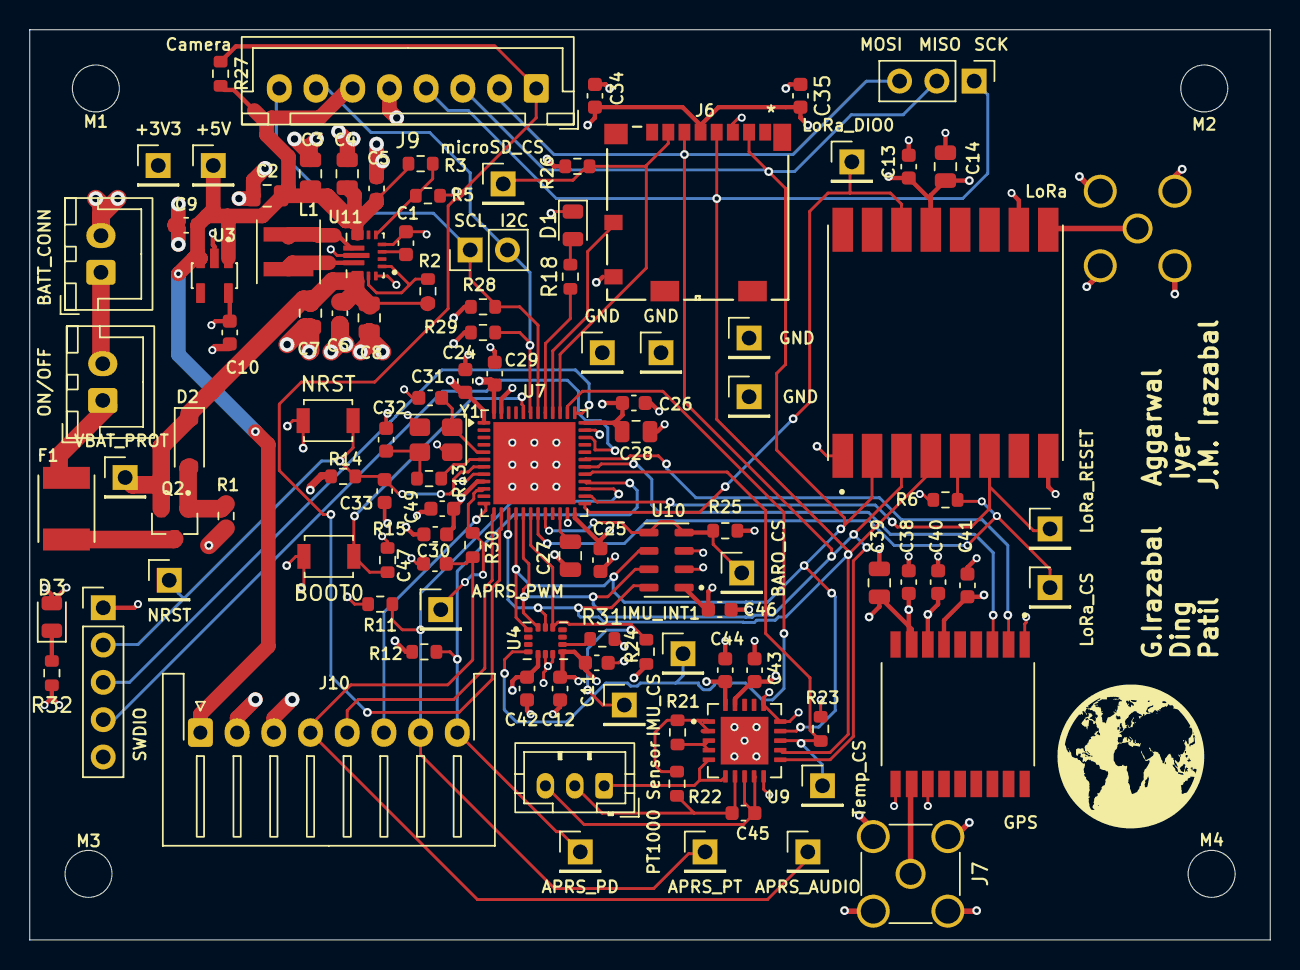
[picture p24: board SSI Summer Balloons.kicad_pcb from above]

Board: 4 copper layers, 84.5 x 62.0 mm, 112 parts (1 on the bottom side), 55 nets.

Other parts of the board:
BOOT0: BOOT0; SW_SPST_B3U-1000P
GPS: MAX-M10S-00B; XCVR_MAX-M10S-00B
LoRa: RFM95W-915S2; XCVR_RFM95W-915S2
M1, M2, M3, M4: MountingHole_3.2mm_M3
NRST: NRST; SW_SPST_B3U-1000P

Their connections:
+3V3: BOOT0.2 (B), GPS.6 (V_BCKP), GPS.7 (V_IO), GPS.8 (VCC), LoRa.13 (3.3V); also elsewhere on the board
/GPS/GPS_RX: GPS.3 (RXD); also elsewhere on the board
/GPS/GPS_TX: GPS.2 (TXD); also elsewhere on the board
/MCU (STM)/BOOT0: BOOT0.1 (A); also elsewhere on the board
/MCU (STM)/LoRa_CS: LoRa.5 (NSS); also elsewhere on the board
/MCU (STM)/LoRa_DIO0: LoRa.14 (DIO0); also elsewhere on the board
/MCU (STM)/LoRa_RESET: LoRa.6 (RESET); also elsewhere on the board
/MCU (STM)/MISO: LoRa.2 (MISO); also elsewhere on the board
/MCU (STM)/MOSI: LoRa.3 (MOSI); also elsewhere on the board
/MCU (STM)/NRST: NRST.2 (B); also elsewhere on the board
/MCU (STM)/SCK: LoRa.4 (SCK); also elsewhere on the board
GND: GPS.1 (GND), GPS.10 (GND), GPS.12 (GND), LoRa.1 (GND), LoRa.8 (GND), LoRa.10 (GND), NRST.1 (A); also elsewhere on the board
unnamed 39: LoRa.9 (ANT); also elsewhere on the board
unnamed 40: GPS.11 (RF_IN); also elsewhere on the board

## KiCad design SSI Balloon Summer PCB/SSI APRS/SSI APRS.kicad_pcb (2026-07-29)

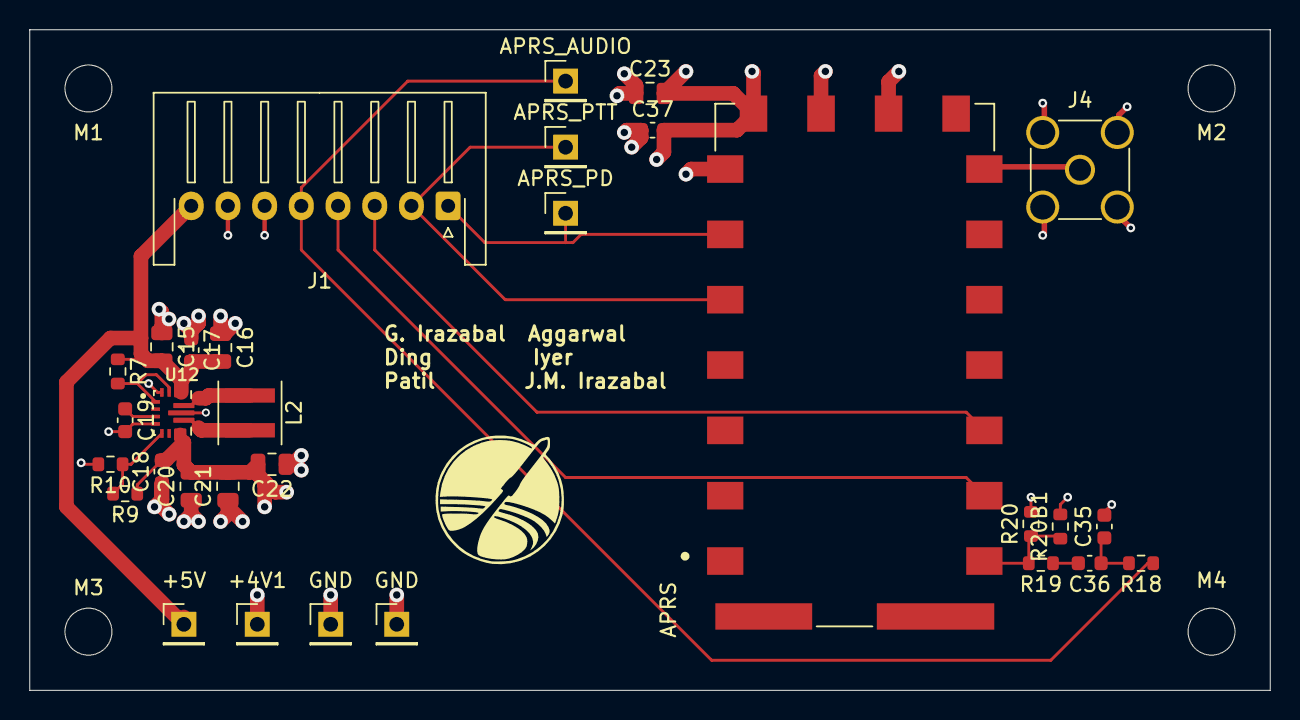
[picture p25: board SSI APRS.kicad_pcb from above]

Board: 4 copper layers, 84.5 x 45.0 mm, 35 parts (0 on the bottom side), 17 nets.

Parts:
+4V1, +5V: Conn_01x01; PinHeader_1x01_P2.54mm_Vertical
APRS: DRA818V; DORJI_DRA818V
APRS_AUDIO: Conn_01x01; PinHeader_1x01_P2.54mm_Vertical
APRS_PD: Conn_01x01; PinHeader_1x01_P2.54mm_Vertical
APRS_PTT: Conn_01x01; PinHeader_1x01_P2.54mm_Vertical
C15, C16, C23: 10uF; C_0805_2012Metric
C17, C18: 10uF; C_0603_1608Metric
C19, C36, C37: 100nF; C_0603_1608Metric
C20, C21, C22: 22uF; C_0805_2012Metric
C35: 10nF; C_0603_1608Metric
GND: Conn_01x01; PinHeader_1x01_P2.54mm_Vertical
GND#2: Conn_01x01; PinHeader_1x01_P2.54mm_Vertical
J1: Conn_01x08; JST_XH_S8B-XH-A-1_1x08_P2.50mm_Horizontal
J4: APRS antenna; SMA_Amphenol_901-144_Vertical
L2: 1.5 uH; L_Coilcraft_XxL4020
M1, M2, M3, M4: MountingHole_3.2mm_M3
R7, R19: 10k; R_0603_1608Metric
R9: 510k; R_0603_1608Metric
R10: 120k; R_0603_1608Metric
R18: 1k; R_0603_1608Metric
R20: 470; R_0603_1608Metric
R20B1: TBD; R_0603_1608Metric
U12: TPS63070RNMR; VREG_TPS63070RNMR

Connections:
+4V1: +4V1.1 (Pin_1_1), APRS.8 (VBAT), C18.2, C20.2, C21.2, C22.2, C23.2, C37.2, R9.1, U12.7_8 (VOUT)
+5V: +5V.1 (Pin_1_1), C15.2, C16.2, C17.2, J1.8, R7.1, U12.12_13 (VIN)
/APRS_AUDIO: APRS_AUDIO.1 (Pin_1_1), J1.5, R18.1
/APRS_PD: APRS.6 (PD), APRS_PD.1 (Pin_1_1), J1.1
/APRS_PTT: APRS.5 (PTT), APRS_PTT.1 (Pin_1_1), J1.2
/APRS_RX: APRS.16 (RXD), J1.3
/APRS_TX: APRS.17 (TXD), J1.4
GND: APRS.7 (H/L), APRS.9 (GND), APRS.10 (GND), C15.1, C16.1, C17.1, C18.1, C19.2, C20.1, C21.1, C22.1, C23.1, C35.2, C37.1, GND.1 (Pin_1_1), GND#2.1 (Pin_1_1), J1.6, J1.7, J4.2 (Ext), R10.2, R20.2, R20B1.2, U12.4 (GND), U12.10 (PGND), U12.15 (VSEL)
unnamed: C35.1, C36.1, R18.2
unnamed: C36.2, R19.1
unnamed: APRS.12 (ANT), J4.1 (In)
unnamed: APRS.18 (MIC_IN), R19.2, R20.1, R20B1.1
unnamed: R7.2, U12.1 (PS/SYNC), U12.14 (EN)
unnamed: R9.2, R10.1, U12.5 (FB)
unnamed: L2.1, U12.11 (L1)
unnamed: L2.2, U12.9 (L2)
unnamed: C19.1, U12.3 (VAUX)

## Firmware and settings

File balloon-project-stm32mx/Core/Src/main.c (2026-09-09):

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
/* Includes ------------------------------------------------------------------*/
#include "main.h"
#include "fatfs.h"

/* USER CODE BEGIN Includes */
#include "app.h"
#include "spi_bus.h"
/* USER CODE END Includes */

I2C_HandleTypeDef hi2c1;

SPI_HandleTypeDef hspi1;

TIM_HandleTypeDef htim2;

UART_HandleTypeDef huart1;
UART_HandleTypeDef huart2;

void SystemClock_Config(void);
static void MX_GPIO_Init(void);
static void MX_I2C1_Init(void);
static void MX_SPI1_Init(void);
static void MX_TIM2_Init(void);
static void MX_USART1_UART_Init(void);
static void MX_USART2_UART_Init(void);
/**
  * @brief  The application entry point.
  * @retval int
  */
int main(void)
{

  /* MCU Configuration--------------------------------------------------------*/

  /* Reset of all peripherals, Initializes the Flash interface and the Systick. */
  HAL_Init();

  /* Configure the system clock */
  SystemClock_Config();

  /* Initialize all configured peripherals */
  MX_GPIO_Init();
  MX_I2C1_Init();
  MX_SPI1_Init();
  MX_TIM2_Init();
  MX_USART1_UART_Init();
  MX_USART2_UART_Init();
  MX_FATFS_Init();
  /* USER CODE BEGIN 2 */
  (void)spi_bus_init(&hspi1);
  (void)app_init();

  /* Boot indicator: PB5 LED on, and left on for the rest of the run.
     Placed after app_init() so a lit LED means "booted, clocks up, and all
     sensor init completed".

     Standalone-boot diagnostic: powered from battery with no ST-LINK attached,
     this LED should light and stay lit. Lit under the debugger but dark on
     battery means the chip is not executing from flash when it boots on its
     own — check BOOT0 (must be low), the battery rail under load, and NRST.

     PB5 is not in the .ioc, so configure it directly here. */
  GPIOB->MODER  &= ~(3U << (5 * 2));  /* clear PB5 mode bits */
  GPIOB->MODER  |=  (1U << (5 * 2));  /* PB5 = general-purpose output */
  GPIOB->OTYPER &= ~(1U << 5);        /* push-pull */
  GPIOB->BSRR    =  (1U << 5);        /* PB5 high -> LED on, stays on */
  /* USER CODE END 2 */

  /* Infinite loop */
  /* USER CODE BEGIN WHILE */
  while (1)
  {
    /* USER CODE END WHILE */

    /* USER CODE BEGIN 3 */
    app_run();
  }
  /* USER CODE END 3 */
}

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


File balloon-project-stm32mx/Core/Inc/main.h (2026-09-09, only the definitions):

#define APRS_PWM_Pin GPIO_PIN_0
#define APRS_PWM_GPIO_Port GPIOA
#define Cam_CS_Pin GPIO_PIN_4
#define Cam_CS_GPIO_Port GPIOA
#define IMU_CS_Pin GPIO_PIN_0
#define IMU_CS_GPIO_Port GPIOB
#define LoRa_CS_Pin GPIO_PIN_1
#define LoRa_CS_GPIO_Port GPIOB
#define BARO_CS_Pin GPIO_PIN_2
#define BARO_CS_GPIO_Port GPIOB
#define LoRa_DIO0_Pin GPIO_PIN_12
#define LoRa_DIO0_GPIO_Port GPIOB
#define LoRa_DIO0_EXTI_IRQn EXTI15_10_IRQn
#define LoRa_RESET_Pin GPIO_PIN_13
#define LoRa_RESET_GPIO_Port GPIOB
#define APRS_PTT_Pin GPIO_PIN_14
#define APRS_PTT_GPIO_Port GPIOB
#define APRS_PD_Pin GPIO_PIN_15
#define APRS_PD_GPIO_Port GPIOB
#define Temp_CS_Pin GPIO_PIN_8
#define Temp_CS_GPIO_Port GPIOA
#define IMU_INT1_Pin GPIO_PIN_15
#define IMU_INT1_GPIO_Port GPIOA
#define IMU_INT1_EXTI_IRQn EXTI15_10_IRQn
#define microSD_CS_Pin GPIO_PIN_3
#define microSD_CS_GPIO_Port GPIOB
#define microSD_detect_Pin GPIO_PIN_4
#define microSD_detect_GPIO_Port GPIOB

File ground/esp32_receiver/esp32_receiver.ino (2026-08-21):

/*
 * SSI Balloon — ESP32 ground station receiver
 *
 * Receives packet v1 telemetry from the flight computer's RFM95W and prints
 * decoded fields over USB serial at 115200 baud.
 *
 * Hardware: ESP32 dev board + Adafruit RFM95W LoRa breakout (product 3072)
 *           + 915 MHz antenna (see wiring table in ground/README.md).
 *
 * Library:  "LoRa" by Sandeep Mistry  (Library Manager -> search "LoRa")
 *           Do NOT use RadioHead: RH_RF95 prepends a 4-byte TO/FROM/ID/FLAGS
 *           header to every packet, which the flight firmware does not send.
 *           This library transmits and receives raw payloads.
 *
 * Every modem parameter below must match balloon-project-stm32mx/App/Inc/lora.h.
 * If the flight side changes, change it here too or nothing will decode.
 */

#include <SPI.h>
#include <LoRa.h>

/* ---- Wiring: change these to match how you wired the breakout ----
 *
 * PIN_DIO0 is set to -1 because this sketch polls with LoRa.parsePacket()
 * rather than using an interrupt, so the breakout's "G0" pin can be left
 * unconnected. Only set a real pin here if you switch to LoRa.onReceive().
 *
 * Avoid GPIO2 for DIO0: it is a boot-strapping pin, and DIO0 is driven by
 * the radio, so the radio could hold it at an arbitrary level while the
 * ESP32 is deciding how to boot.
 */
#define PIN_SCK    18
#define PIN_MISO   19
#define PIN_MOSI   15
#define PIN_CS      5
#define PIN_RST     4
#define PIN_DIO0   -1   /* breakout "G0" — not needed when polling */

/* ---- Modem settings: must match flight lora.h ---- */
#define LORA_FREQ_HZ      915000000L  /* LORA_FREQ_HZ */
#define LORA_SF                    8  /* RegModemConfig2 0x84 -> SF8 */
#define LORA_BW_HZ            125000  /* RegModemConfig1 0x72 -> 125 kHz */
#define LORA_CR_DENOM              5  /* RegModemConfig1 0x72 -> CR 4/5 */
#define LORA_SYNC_WORD          0x12  /* LORA_SYNC_WORD (private, not LoRaWAN 0x34) */
#define LORA_PREAMBLE_LEN          8  /* LORA_PREAMBLE_LEN */

/* ---- Packet v1 layout: must match App/Inc/packet.h ---- */
#define PACKET_V1_LEN       28
#define PACKET_V1_VERSION 0x01
#define PACKET_V1_CRC_LEN   26  /* CRC covers bytes 0..25 */
#define PACKET_V1_BATT_NA 0xFFFF

typedef struct {
  uint8_t  version;
  uint8_t  mission_state;
  uint16_t seq;
  uint32_t time_ms;
  int32_t  lat_e7;
  int32_t  lon_e7;
  uint16_t gps_alt_m;
  int16_t  baro_alt_m;
  int16_t  temp_c_x100;
  uint16_t batt;
  uint8_t  flags;
  uint8_t  sats;
} packet_v1_t;

/* Big-endian readers — the wire format is MSB first. */
static uint16_t be_u16(const uint8_t *b) {
  return ((uint16_t)b[0] << 8) | (uint16_t)b[1];
}
static uint32_t be_u32(const uint8_t *b) {
  return ((uint32_t)b[0] << 24) | ((uint32_t)b[1] << 16) |
         ((uint32_t)b[2] << 8)  | (uint32_t)b[3];
}
static int16_t be_i16(const uint8_t *b) { return (int16_t)be_u16(b); }
static int32_t be_i32(const uint8_t *b) { return (int32_t)be_u32(b); }

/* CRC-16/CCITT-FALSE: init 0xFFFF, poly 0x1021, MSB first.
   Mirrors packet_crc16() in App/Inc/packet.h. */
static uint16_t packet_crc16(const uint8_t *data, uint16_t len) {
  uint16_t crc = 0xFFFF;
  for (uint16_t i = 0; i < len; i++) {
    crc ^= (uint16_t)data[i] << 8;
    for (uint8_t bit = 0; bit < 8; bit++) {
      crc = (crc & 0x8000) ? (uint16_t)((crc << 1) ^ 0x1021)
                           : (uint16_t)(crc << 1);
    }
  }
  return crc;
}

/* Returns false on wrong length, wrong version, or CRC mismatch. */
static bool packet_v1_unpack(const uint8_t *in, uint16_t len, packet_v1_t *out) {
  if (len != PACKET_V1_LEN)            return false;
  if (in[0] != PACKET_V1_VERSION)      return false;

  uint16_t crc_stored = be_u16(&in[26]);
  uint16_t crc_calc   = packet_crc16(in, PACKET_V1_CRC_LEN);
  if (crc_stored != crc_calc)          return false;

  out->version       = in[0];
  out->mission_state = in[1];
  out->seq           = be_u16(&in[2]);
  out->time_ms       = be_u32(&in[4]);
  out->lat_e7        = be_i32(&in[8]);
  out->lon_e7        = be_i32(&in[12]);
  out->gps_alt_m     = be_u16(&in[16]);
  out->baro_alt_m    = be_i16(&in[18]);
  out->temp_c_x100   = be_i16(&in[20]);
  out->batt          = be_u16(&in[22]);
  out->flags         = in[24];
  out->sats          = in[25];
  return true;
}

static uint32_t g_rx_total = 0;   /* every packet the radio handed us */
static uint32_t g_rx_valid = 0;   /* those that passed version + CRC */

void setup() {
  Serial.begin(115200);
  while (!Serial && millis() < 3000) { /* wait briefly for USB serial */ }

  Serial.println();
  Serial.println(F("SSI Balloon ground station — packet v1 receiver"));

  SPI.begin(PIN_SCK, PIN_MISO, PIN_MOSI, PIN_CS);
  LoRa.setPins(PIN_CS, PIN_RST, PIN_DIO0);

  if (!LoRa.begin(LORA_FREQ_HZ)) {
    Serial.println(F("ERROR: radio not found."));
    Serial.println(F("Check wiring (CS/RST/G0), 3.3-6V on Vin, and that EN is not pulled low."));
    while (1) { delay(1000); }
  }

  LoRa.setSpreadingFactor(LORA_SF);
  LoRa.setSignalBandwidth(LORA_BW_HZ);
  LoRa.setCodingRate4(LORA_CR_DENOM);
  LoRa.setSyncWord(LORA_SYNC_WORD);
  LoRa.setPreambleLength(LORA_PREAMBLE_LEN);
  LoRa.enableCrc();                 /* flight side sets RxPayloadCrcOn */

  Serial.println(F("Radio up: 915.0 MHz  SF8  BW125k  CR4/5  sync 0x12  CRC on"));
  Serial.println(F("Listening..."));
  Serial.println();
}

void loop() {
  int len = LoRa.parsePacket();
  if (len == 0) {
    return;                          /* nothing received this pass */
  }

  uint8_t buf[PACKET_V1_LEN];
  int n = 0;
  while (LoRa.available() && n < (int)sizeof(buf)) {
    buf[n++] = (uint8_t)LoRa.read();
  }
  while (LoRa.available()) { (void)LoRa.read(); }   /* drain any excess */

  int   rssi = LoRa.packetRssi();
  float snr  = LoRa.packetSnr();
  g_rx_total++;

  packet_v1_t p;
  if (!packet_v1_unpack(buf, (uint16_t)n, &p)) {
    Serial.printf("[%lu] BAD PACKET  len=%d  rssi=%d dBm  snr=%.1f dB  raw=",
                  (unsigned long)g_rx_total, n, rssi, snr);
    for (int i = 0; i < n; i++) Serial.printf("%02x", buf[i]);
    Serial.println();
    return;
  }

  g_rx_valid++;

  Serial.printf("[%lu/%lu] seq=%u  t=%lu ms  state=%u\n",
                (unsigned long)g_rx_valid, (unsigned long)g_rx_total,
                p.seq, (unsigned long)p.time_ms, p.mission_state);
  Serial.printf("    gps      : %.7f, %.7f   alt=%u m   sats=%u\n",
                p.lat_e7 / 1e7, p.lon_e7 / 1e7, p.gps_alt_m, p.sats);
  Serial.printf("    baro alt : %d m\n", p.baro_alt_m);
  Serial.printf("    temp     : %.2f C\n", p.temp_c_x100 / 100.0);
  if (p.batt == PACKET_V1_BATT_NA) {
    Serial.println(F("    batt     : n/a"));
  } else {
    Serial.printf("    batt     : %u mV\n", p.batt);
  }
  Serial.printf("    flags    : 0x%02x\n", p.flags);
  Serial.printf("    link     : rssi=%d dBm  snr=%.1f dB\n", rssi, snr);
  Serial.println();
}

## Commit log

2026-06-19 PCB uploading
    [GPS.kicad_sch, MCU.kicad_sch, Power.kicad_sch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]
2026-06-19 Giving all info for PCB
    [AP2112K-3.3TRG1.step, DMG2305UX-7.step, DW01A.step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]
2026-06-19 Worked on LoRa and APRS
    [DRA818V.step, Power.kicad_sch, RFM95W-915S2.step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]
2026-06-20 Added 4.1V rail for APRS
    [Power.kicad_sch, SSI Summer Balloons.kicad_sch]
2026-06-20 APRS work - MIC_IN pin left
    [Radio.kicad_sch]
2026-06-20 MCU sheet initial draft
    [ABM8W-12.0000MHZ-8-K1Z-T3.step, MCU.kicad_sch]
2026-06-21 Added CS pins for SPI and hierarchical labels to MCU sheet
    [MCU.kicad_sch, SSI Summer Balloons.kicad_sch]
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2026-06-26 Standardized power symbols, added microSD sheet, and standardized hierarchical labels
    [1040310811.step, MCU.kicad_sch, Power.kicad_sch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]
2026-06-30 Finished GPS
    [GPS.kicad_sch, MCU.kicad_sch, Power.kicad_sch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]
2026-06-30 Tidied some labels up
    [Radio.kicad_sch, SSI Summer Balloons.kicad_sch]
2026-06-30 adding IMU footprint+symbol
    [MCU.kicad_sch, SSI Summer Balloons.kicad_sch]
2026-07-01 Finished sensors + tidied up schematic
    [AP2112K-3.3TRG1.step, ICM-42688-P.step, MAX31865ATP_T.step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]
2026-07-01 fixed TX and RX
    [MCU.kicad_sch]
2026-07-02 Fixed I2C and SPI issues
    [MCU.kicad_sch, Sensor.kicad_sch, microSD.kicad_sch]
2026-07-02 Added APRS_AUDIO
    [MCU.kicad_sch, Radio.kicad_sch, SSI Summer Balloons.kicad_sch]
2026-07-03 Minor tweaks, renamed some pins
    [MCU.kicad_sch, Power.kicad_sch, SSI Summer Balloons.kicad_sch]
2026-07-06 Fixed ERC - no ERC errors
    [GPS.kicad_sch, Power.kicad_sch, Radio.kicad_sch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]
2026-07-07 finished footprints for PWR sheet
    [Power.kicad_sch]
2026-07-07 Revised power sheet
    [Power.kicad_sch]
2026-07-08 Layout placement for every sheet except PWR and SD card
    [GPS.kicad_sch, MCU.kicad_sch, Power.kicad_sch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]
2026-07-08 finished SD card placement - only Power sheet left
    [SSI Summer Balloons.kicad_pcb]
2026-07-08 Reviewed sensor sheet
    [GPS.kicad_sch, MCU.kicad_sch, Power.kicad_sch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]
2026-07-08 Reviewed Radio, GPS sheet and minor tweak on power sheet
    [Power.kicad_sch, SSI Summer Balloons.kicad_pcb]
2026-07-08 Finished power sheet layout organization
    [Power.kicad_sch]
2026-07-09 layout board layers + rules
    [SSI Summer Balloons.kicad_pcb]
2026-07-09 Overhauled power symbols for consistency and ERC
    [GPS.kicad_sch, MCU.kicad_sch, Power.kicad_sch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]
2026-07-09 Removed sketchy R4 footprint
    [Power.kicad_sch, SSI Summer Balloons.kicad_pcb]
2026-07-09 Routing for power sheet
    [Power.kicad_sch, SSI Summer Balloons.kicad_pcb]
2026-07-09 Routed 4v1 and 3v3 rail
    [Power.kicad_sch, SSI Summer Balloons.kicad_pcb]
2026-07-09 Halfway done connecting MCU traces
    [MCU.kicad_sch, SSI Summer Balloons.kicad_pcb]
2026-07-10 fixed footprints
    [GPS.kicad_sch, MCU.kicad_sch, Radio.kicad_sch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]
2026-07-10 Routed IMU, Temp, Baro, SD
    [SSI Summer Balloons.kicad_pcb]
2026-07-10 Edits to PCB placement + traces - RF and GPS next
    [MCU.kicad_sch, SSI Summer Balloons.kicad_pcb, Sensor.kicad_sch]
2026-07-11 GPS and LoRa on PCB
    [SSI Summer Balloons.kicad_pcb]
2026-07-11 Routed most of SPI
    [SSI Summer Balloons.kicad_pcb]
2026-07-14 APRS seperate board done
    [GPS.kicad_sch, MCU.kicad_sch, Power.kicad_sch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]
2026-07-14 Various rewiring: SWD, microSD, APRS JST
    [MCU.kicad_sch, SSI APRS.kicad_pcb, SSI APRS.kicad_sch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]
2026-07-14 SPI traces clean up
    [SSI Summer Balloons.kicad_pcb]
2026-07-14 Cleaned APRS Filter up and adding Testing points
    [GPS.kicad_sch, MCU.kicad_sch, Power.kicad_sch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]
2026-07-15 Finished test points
    [MCU.kicad_sch, SSI APRS.kicad_pcb, SSI APRS.kicad_sch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]
2026-07-15 Silkscreened it all over
    [SSI Summer Balloons.kicad_pcb]
2026-07-16 Minor tweak to GPS coax conn
    [SSI Summer Balloons.kicad_pcb]
2026-07-17 Added Headers for testing, finalizing PCB
    [MCU.kicad_sch, Power.kicad_sch, Radio.kicad_sch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]
2026-07-18 moved two pins for SD card
    [SSI Summer Balloons.kicad_pcb]
2026-07-18 APRS naming convention stuff
    [SSI APRS.kicad_pcb]
2026-07-18 Cleared space for microSD, organized SPI tracks
    [SSI Summer Balloons.kicad_pcb]
2026-07-18 More silkscreen organization, combined some pinheaders
    [MCU.kicad_sch, Power.kicad_sch, Radio.kicad_sch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]
2026-07-20 Updated antenna connector
    [GPS.kicad_sch, Radio.kicad_sch, SSI APRS.kicad_pcb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]
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2026-07-23 BOM for APRS board done - motherboard next
    [SSI APRS.kicad_sch]
2026-07-24 finished finding all parts on JLCPCB - finalizing BOM then order
    [GPS.kicad_sch, MCU.kicad_sch, Power.kicad_sch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]
2026-07-25 PCB finally done i think and ready to order
    [GPS.kicad_sch, MCU.kicad_sch, Power.kicad_sch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]
2026-07-29 Board done but we have a price crisis so might have to change things
    [GPS.kicad_sch, MCU.kicad_sch, Power.kicad_sch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]
2026-08-05 Foundation and Tooling
    * Created App/ tree
    * Integrated Makefile to account for updated directory format
    * Updated USART1 baud to 9600
    * Established Error Flag framework
    * Updated documentation for coding standards and finished exit criteria
    [app.c, balloon-project-stm32mx.ioc, main.c]
2026-08-06 F1 SPI bus services
    * Updated Clock policy to ensure all components run properly and fixed ide config issues
    * Set up Transfer API for proper flow
    * Added register helpers for future ease in SPI framing
    [balloon-project-stm32mx.ioc, main.c, spi_bus.c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]
2026-08-09 IMU Sensor (#4)
    * Set up IMU init, error flags, and sensor files
    * set up firmware guidelines, bench backlog, and testing rules for future development
    * Finished configuration and sample reading for IMU sensor. Software verificaiton done
    - Check with physical board remains
    [app.c, imu.c]
2026-08-15 Barometer Software
    * Set up reset and PROM for barometer
    * Set up conversion sequences to read data
    * Implemented compensation math to ensure readings from sensor are accurate and usable
    * Completed API integration and updated documentation to follow software and hardware gate split
    [app.c, baro.c, baro.h]
2026-08-19 Feature/temperature (#6)
    * Set up the config for temeprature sensor
    * Set up reading raw data and conversion to get usable sensor data
    * Set up API and tested exit criteria
2026-08-19 Feature/gps (#7)
    * Set up GPS RX path
    * Set up GPS Sentence parser
    * Set up fix validity
    [app.c, balloon-project-stm32mx.ioc, gps.c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]
2026-08-20 LoRa
    * Set up LoRa hardware reset and version probe
    * Set up radio config
    * Set up packet TX
    * Set up ground station work
    [app.c, lora.c]
2026-08-20 spi_bus: add per-device SPI clock mode switching
    SPI1 is configured as Mode 0 (CPOL=0, CPHA=0), which the ICM-42688-P and
    MS5611 both accept. The MAX31865 does not: its datasheet supports only
    Mode 1 or Mode 3 (CPHA=1). Sampling on the wrong clock edge shifts every
    bit by one clock relative to what the device expects.
    Add spi_bus_set_mode() alongside the existing spi_bus_set_prescaler() so a
    driver can switch polarity/phase for its own transfers and restore the bus
    default afterwards, without disturbing the other slaves on SPI1.
    [spi_bus.c, spi_bus.h]
2026-08-20 temp: fix MAX31865 register R/W bit convention
    temp_read_reg()/temp_write_reg() called spi_bus_read_reg8()/write_reg8(),
    which apply the ICM-42688-P convention (read = reg|0x80, write = reg&0x7F).
    The MAX31865 inverts this: write = reg|0x80, read = reg with MSB clear.
    spi_bus.h documents that other slaves must frame their own transfers.
    The effect was that every access did the opposite of what was intended --
    temp_write_reg(CONFIG, ...) issued a read, and temp_read_reg(CONFIG, ...)
    issued a write of 0x00 into the config register and returned 0x00. The
    same inverted bit was set on the RTD burst read address.
    Frame the transfers directly via spi_bus_transfer() with the correct
    addressing, an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
    [temp.c]
2026-08-20 ide: add STM32CubeIDE project files for the Makefile build
    Importing this Makefile project into STM32CubeIDE via the STM32 wizard
    fails silently (the wizard targets CubeMX-managed projects). These CDT
    files let it be imported with File > Import > Existing Projects instead,
    building through the existing Makefile rather than a generated one.
    The toolchain PATH lives in .settings/, which is gitignored, so each
    developer still sets their own: Properties > C/C++ Build > Environment,
    add PATH with the directory containing arm-none-eabi-gcc.
    Debug uses a GDB Hardware Debugging launch (ST-LINK GDB server on 61234),
    not the STM32 launch type, which rejects non-managed build configurations.
    Co-Auth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
2026-08-21 lora: fix RFM95W register R/W bit convention
    lora_read_reg()/lora_write_reg() called spi_bus_read_reg8()/write_reg8(),
    which apply the ICM-42688-P convention (read = reg|0x80). The RFM95W datasheet
    (section 4.3) defines the address byte's bit 7 as "wnr", which is 1 for write
    and 0 for read -- the inverse. Every register access did the opposite of what
    was intended.
    lora_write_fifo() had the same inversion: it sent RegFifo with no write bit, so
    the radio saw a read where a FIFO write was meant. That path is only reached
    during transmit and had never run.
    Datasheet section 4.3 also specifies CPOL=0, CPHA=0, which is the SPI1 default,
    so no per-device mode switch is needed here (unlike the MA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
    [lora.c]
2026-08-21 app: add bench telemetry beacon over LoRa
    app_run() now packs a packet v1 from whatever sensors are healthy and transmits
    it every 5 s. Sensors that are unhealthy or have no fix leave their fields
    zeroed, so the RF link can be exercised indoors with no GPS lock.
    Counters and the last built packet have external linkage and are volatile so
    they can be watched in the debugger from any stop location:
    g_beacon_attempts, g_beacon_ok, g_beacon_fail, g_beacon_fields, g_beacon_wire.
    Verified on hardware: attempts=3, ok=3, fail=0 -- the radio accepted each
    packet and asserted TxDone.
    [app.c]
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2026-08-21 ground: add ESP32 LoRa receiver and ST-LINK server helper
    ground/esp32_receiver/ is an Arduino sketch for an ESP32 plus an Adafruit
    RFM95W breakout (product 3072). It receives packet v1, validates the CRC, and
    prints decoded telemetry with RSSI/SNR over USB serial at 115200 -- no WiFi or
    BLE. Modem settings mirror App/Inc/lora.h exactly; the README documents wiring,
    setup, and the RadioHead incompatibility (it prepends a 4-byte header the
    flight firmware does not send).
    scripts/stlink-server.sh starts, stops, and reports the ST-LINK GDB server that
    the GDB Hardware Debugging launch expects on port 61234. It locates the CubeIDE
    plugin paths dynamically and retries the SWD attach, which inter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
    [esp32_receiver.ino]
2026-08-22 gps: add RX diagnostic counters for bench bring-up
    gps_init() only enables the USART1 RX interrupt; it cannot detect whether a
    module is attached, so gps_is_ok() returning true is not evidence of a working
    GPS. With no fix, a healthy module and an unplugged one produce identical
    telemetry: zeroed lat/lon and sats.
    Add counters that separate the failure modes, since each needs a different fix:
    no bytes at all (wiring, power, TX/RX swapped), bytes but no lines (baud
    mismatch), lines but no sentences (checksum failures), or sentences but no fix
    (needs sky view). g_gps_last_line holds the raw NMEA for inspection.
    External linkage and volatile so they resolve in the debugger from any stop
    locat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
    [gps.c]
2026-08-22 build: fix compile errors introduced with the microSD work
    main did not build. Six mechanical errors, no behaviour changed:
    Makefile
    - C_SOURCES lost the line-continuation backslashes after spi_bus.c and
    lora.c, which truncated the variable and made make read the next line as
    a rule ("missing separator"). This alone broke the whole build.
    - sd_spi.c was never added to C_SOURCES, so SD_SPI_* did not link.
    Core/Src/main.c
    - ICM_CS_GPIO_Port / ICM_CS_Pin do not exist; the generated names are
    IMU_CS_GPIO_Port / IMU_CS_Pin.
    - snprintf and strlen used without <stdio.h> / <string.h>.
    FATFS/Target/user_diskio.c
    - Called SD_SPI_Read; sd_spi.c defines SD_SPI_ReadBlocks.
    App/S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
    [main.c, sd_spi.c]
2026-08-22 main: guard SD writes when no card, and drop the duplicated loop delay
    Two problems that only appear with no SD card inserted, which is the normal
    bench configuration while testing GPS.
    f_write(&fil, ...) ran unconditionally in the superloop. When f_mount or
    f_open fails, "fil" is an uninitialised FIL passed straight into FatFs --
    undefined behaviour, and capable of hanging the loop. Track a sd_ready flag
    that is only set once both the mount and the open succeed, and skip the raw
    file writes otherwise. sdlog_write_sample() already guards itself on
    sd_is_mounted, so that path was unaffected.
    The loop also had two HAL_Delay(100) calls, one from each half of the merged
    code, giving a 200 ms p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
    [main.c]
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

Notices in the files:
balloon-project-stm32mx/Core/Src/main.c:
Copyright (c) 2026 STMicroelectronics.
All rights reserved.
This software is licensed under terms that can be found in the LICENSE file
